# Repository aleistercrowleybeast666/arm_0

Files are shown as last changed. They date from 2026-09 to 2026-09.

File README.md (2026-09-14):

# arm_0

六轴机械臂机械 CAD。当前唯一正式主工程为 **[mechanical/freecad/arm_0.FCStd](mechanical/freecad/arm_0.FCStd)**，FreeCAD 文档标签为 `arm_0 | Prototype 0`。

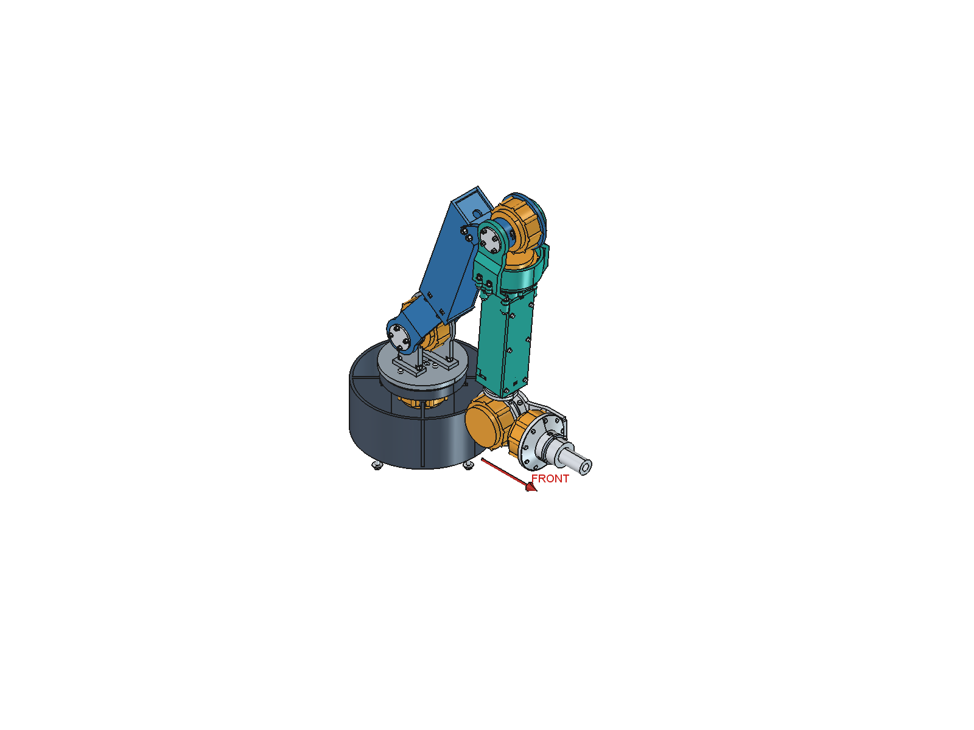
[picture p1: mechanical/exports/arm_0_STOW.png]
arm_0 前折 STOW


当前进度：Prototype 0冻结前紧固与首次审图整理。当前CSV和V4验证为本轮依据，ZIP由白名单脚本单独生成并忽略于Git。

## 当前入口

| 内容 | 文件 |
|---|---|
| 我们自己的主装配 | [arm_0.FCStd](mechanical/freecad/arm_0.FCStd) |
| 参数 | [arm_0_parameters.json](mechanical/arm_0_parameters.json) |
| 完整 STEP | [arm_0.step](mechanical/exports/arm_0.step) |
| 冻结拓扑与当前审图报告 | [arm_0_v3_review.md](mechanical/docs/arm_0_v3_review.md) |
| 装配顺序 | [assembly_concept.md](mechanical/docs/assembly_concept.md) |
| 待解决事项 | [unresolved_issues.md](mechanical/docs/unresolved_issues.md) |
| 文件清单 | [arm_0_files.md](mechanical/docs/arm_0_files.md) |
| PAROL6 参考装配（仅本地） | `mechanical/freecad/PAROL6_reference_assembly.FCStd` |
| CyberGear 参考 | `CyberGear_Detail.FCStd` 与 `CyberGear_Envelope.FCStd` |

旧侧向错层方案完整归档在 [mechanical/legacy/v2](mechanical/legacy/v2/README.md)，标记为 SUPERSEDED。上一个35 mm腕距的大框腕部保存在 [V3腕部快照](mechanical/legacy/v3_box_wrist/README.md)。第一阶段 `Arm_v1_*` 文件也仅为历史。它们的姿态和验证结果不适用于 V3。

## V3 结构

- 当前尺寸为180 / 320 / 290 / 60 / 86 / 90 mm；用户确认将J5→J6的Flange从35改为86 mm。原轴序/转向保持，两根主体盒梁回到Y=0。
- J2由大臂双叉包住，J3由小臂双叉包住；短输出hub加对侧短轴颈，取消长贯穿传动轴。
- J3定子仍固定在大臂。J4电机包络中心前移到距J3约63.75 mm处，扭矩管随roll转动，将动力传到腕部。
- J5/J6在伸直姿态前后排列，移除两层大框；J6_OnePieceConnector是一体金属连接件，J5采用输出侧可拆轴承座。工具接头可拆。
- 采用前折STOW；HOME为其附近的小幅前向展开。启动路径使用不超过2°的关节插值采样检查，不能理解为解析连续碰撞证明或实机安全认证。

当前为工程粗模与静态试装候选。电机接口为REFERENCE-DERIVED / HARDWARE VERIFY；轴承未采购定型，载荷、打印工艺和金属件加工配合尚待验证。J2额定转矩问题仍待解决；单侧金属连接件的刚度、夹紧和轴承力矩能力也需核算。Flange变化后的姿态和包络已重算，ArmDesigner中的历史参数不会自动同步。

## 使用 FreeCAD

打开 `arm_0.FCStd`，选择 PoseController 的 CurrentPose，再运行 `mechanical/scripts/SetArm0Pose.FCMacro`。仅修改下拉框不会自动移动实体。

修改 MasterParameters 后运行 `RebuildArm0.FCMacro`，生成CUSTOM副本并另存；表格不会自动重建几何，也不会写回JSON。原基线中Flange已按本轮授权调整为86 mm，该尺寸更改后需重新验证完整运动；其余五项尺寸保持锁定。本次冻结整理不重新搜索姿态；局部修改后复核已冻结的四姿态与两条启动路径。

当前复核与交接脚本：`validate_assembly_arm_0.py --full`、`handoff_arm_0.py`、`tables_arm_0.mjs`、`ReviewArm0.FCMacro`、`review_freeze_arm_0.py`、`pack_arm_0.py`。FreeCAD脚本使用FreeCAD自带Python；CSV脚本使用配置了@oai/artifact-tool的Node运行时。先通过几何与拆装检查，再导出、渲染、提交代码，最后白名单打包，ZIP不推送。

`ReviewArm0.FCMacro`用于生成原生CAD截图，应在独立FreeCAD进程运行，结束后关闭该进程。参考几何不参与主模型构建，参考研究需要的额外下载见 [来源记录](mechanical/docs/reference_license_notes.md)。`reference/`、原始SolidWorks文件、含上游网格的参考文件、说明书摘录、缓存和备份均不推送。

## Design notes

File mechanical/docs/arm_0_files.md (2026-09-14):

# arm_0 当前文件入口

- mechanical/freecad/arm_0.FCStd：我们自己的正式主CAD，Prototype 0。
- mechanical/exports/arm_0.step：当前HOME整机；同目录四姿态与J2/J3/J4/腕部PNG由ReviewArm0.FCMacro生成。
- mechanical/arm_0_parameters.json：冻结尺寸/姿态与图片来源硬件参数。
- mechanical/docs/fastener_schedule.csv、arm_0_BOM.csv：当前紧固件接口和物料表。
- mechanical/docs/assembly_manifest.csv、joint_datums.csv、parameter_summary.csv：SolidWorks重装与轴基准。
- analysis/v4/assembly_validation.json：本轮含紧固件的完整几何/拆装检查；同目录handoff_export_checks.json记录STEP回读。
- mechanical/handoff/solidworks：白名单交接暂存目录，Git忽略。
- dist/arm_0_SW_handoff_20260914.zip及.sha256：首次审图ZIP及哈希，Git忽略，单独交接。

reference目录、PAROL6参考装配和CyberGear原始详细参考仅供本地参考；不是我们自己的机械臂，也不进入Git或ZIP。旧版几何、旧搜索与analysis/v3等历史报告保留用于追溯，不应用于本轮改动后的紧固装配。当前检查以analysis/v4为准。

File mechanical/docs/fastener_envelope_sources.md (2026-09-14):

# 标准紧固件包络依据

仅使用M3/M4/M5。CAD用简化头部、光杆、垫片和螺母，不建真实牙型。螺杆显示直径为公称值减0.2 mm，啮合段用简化芯径；结构通孔仍按Ø3.4/4.5/5.5 mm建模。该简化不改变M3/M4/M5采购规格，实际螺纹与全直径配合需试装复核。螺钉长度尚未采购定型；CAD中的夹层与1 mm电机螺纹占位用于空间审查，不能解读为推荐有效旋入深度。

|规格|内六角头直径/高|六角螺母对边/高|防松螺母高|内六角工具对边|
|---|---|---|---|---|
|M3|5.5 / 3|5.5 / 2.4|4|2.5|
|M4|7 / 4|7 / 3.2|5|3|
|M5|8.5 / 5|8 / 4|5|4|

来源：[Performance Fasteners ISO 4762产品尺寸表](https://www.performancefastenersltd.co.uk/_files/ugd/aa5dc8_659865f859d941c2905d0a253d751077.pdf)、[Westfield DIN 985产品尺寸表](https://www.westfieldfasteners.co.uk/Standards/Nut-HexNy-M.html)、[Bossard六角螺母目录](https://bossard.partcommunity.com/3d-cad-models/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)。这是几何包络依据，不代表已经选定供应商品号、材料等级或新版标准认证。

M3/M4垫片占位外径7/9 mm、厚0.5/0.8 mm，M5底座大垫片外径15 mm、厚1 mm；均为待确认的空间包络。螺母采用理想六角外接轮廓，保守覆盖尖角。

打印件正式连接禁止使用热熔铜螺母、塑料攻丝、自攻螺钉或胶粘主承力。金属加工件允许M3/M4内螺纹。螺母槽在拆盖板或按记录拆开子装配后可取出，不形成永久封闭腔。

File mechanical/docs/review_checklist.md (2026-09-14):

# arm_0 第一次审图检查单

| 项目 | 本轮输出 / 判定依据 | 审图动作 |
|---|---|---|
| 轴系冻结 | 180/320/290/60/86/90 mm，UpperLane=FoldLane=0；joint_datums.csv | 核对J1～J6父子与正角轴，不改姿态规避局部问题 |
| 连接与孔用途 | fastener_schedule.csv、hole_function_register.csv | 逐编号对应CAD螺钉、A件通孔与金属接收端；核对是否残留无用途工艺孔 |
| 打印件可拆性 | 可更换螺母、侧向退出槽、盖板最后装 | 按表中前置拆件清单实物试装，确认没有封闭在打印件内的螺母 |
| 四方连接块 | 用户指定M4第五行，90°独立板材接口使用，当前安装0 | 采购后确认真实孔深、内孔是否相交，正面孔端距 |
| 轴承与压盖 | 肩座、M3通孔和金属接收端，独立轴承占位 | 核定轴承型号/预紧/公差，确认拆卸方向、剩余壁厚 |
| J4扭矩管 | 两端支承、金属夹紧、角部线槽 | 检查线槽和旋转件间隙，验证夹紧力与抗滑移 |
| J5/J6 | 前后排列、一体金属连接件、可拆工具接头 | 重点核算单侧刚度、螺钉头凹座与夹紧段 |
| 整机几何 | assembly_validation.json记录四姿态和两条≤2°路径 | 检查最小间隙位置和台面锚栓向下延伸；不能按模型包络推断螺钉长度 |
| 拆装工具 | 直线内六角35 mm预算，螺母12 mm退出包络 | 检查真实扳手弯头/套筒与手部空间；确认分阶段拆装顺序可执行 |
| STEP导入 | 所有文件独立回读；handoff_export_checks.json | 在SolidWorks运行Import Diagnostics并核对实体数和单位 |
| 生产准备 | 当前不发布 | 完成负载、材料、加工、公差、螺钉啮合、实物试装后另行评审 |

CAD自动检查只覆盖模型定义的包络。图纸未核定的硬件数据明确保留TBD；不把待测内容勾选为确认项。

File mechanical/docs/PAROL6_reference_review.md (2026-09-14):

# PAROL6 整体参考装配与结构审查

来源提交 `3892e9c85c1f6d8041cda01c47c9db9d18b30ad8`，根许可证GPLv3。本文件补充上一轮的目录审查，结合URDF、STL、装配手册与BOM。只用于研究，不导入我们的arm_0。

## 已装配的结果

`freecad/PAROL6_reference_assembly.FCStd`，7个可独立显隐的实体网格link：base_link、L1…L6，另有world组。关节保留原名base_joint、L1…L6，保留父子关系、轴向和原点属性。

读取 `PAROL6_URDF/PAROL6/urdf/PAROL6.urdf` 的visual mesh、visual origin、joint origin与axis。按父→子拓扑递推，以全部关节角0作为装配姿态；URDF的RPY使用Rz(yaw)Ry(pitch)Rx(roll)。本库STL数值也是米：例如base网格X范围-0.1775…0.05，因此**STL与关节xyz都乘1000**后进入FreeCAD毫米环境。未混用惯性原点，也未重复加载collision mesh。

已经用FreeCAD生成整体截图 `exports/PAROL6_reference_assembly.png`，形态与手册整体构型一致；导入详情 `analysis/stage2/parol6_import.json`。这是静态参考装配，未验证真实限位、负载和运动学solver。

## J1/J2/J3布置与归属

1. J1：手册59…78页为肩部/转台装配，79…86页为底座。电机、减速器、联轴器、J1_rotation_shaft和皮带分工，不是一个电机外壳直接承受全部回转弯矩。第80页底座安装两只Bearing3，BOM指定HR32907J一类锥滚子轴承。可借鉴独立支承及装配可达性。
2. J2：肩部电机驱动大臂，手册70…76页含成对轴承、J2_shaft和后压板。URDF的L2相对L1偏移(23.420721,0,110.5) mm，RPY绕X约-90°，关节自身轴为+Z，经父变换后成为水平轴。不要把原URDF的局部Z误解成世界竖轴。
3. J3：手册50页在大臂装两只Bearing2；52页安装J3大带轮；53页把Stepper2及20:1减速器装在**大臂上**；56页再连接前臂，92页左右才补装J3传动带。由这些装配步骤可确认其J3驱动固定于父大臂，输出通过皮带到肘轴。电机靠近大臂近端，不等于本项目“CyberGear直接位于肘端”。

URDF的L3相对L2为(0,-180,0) mm，并带约(π,0,-π/2)旋转、局部轴-Z；这提供了180 mm原中心距和分段坐标证据，不能直接照抄到320 mm大臂。

## 折叠与腕部

手册53/56页及原STL显示，大臂是偏置的外侧承力件，前臂/肘部转动件在旁侧连接；轴承、轮和盖板分别布置，避免把两段实体简单堆在同一中心平面。局部轮廓让位、侧面间距与轴向堆叠一起影响折叠。本轮未用参考URDF限位证明任何175°或180°极限。

手册25…36页：J5_part轴承、J5皮带轮及走线孔、前臂壳体和J4_output_pulley。39…47页：肘壳、J4皮带和后轴承压板。20…23页：末端步进电机/10:1减速器与AXK3552型轴向支承。腕部通过独立轴承、近置的正交轴以及远置/侧置传动降低端部堆叠长度，不是三只同规格电机依次串接。

URDF中L4→L5有176.35 mm偏移，L5→L6的joint origin平移为0但转轴正交；相交轴不意味着实际壳体和电机没有体积。这个事实可用于检查我们的腕部布局，不能据此把其腕长或减速器尺寸照搬。

## 借鉴与不匹配

可借鉴：分体壳和维护盖、轴承止口/压板、把主要弯矩引入独立支承、先装驱动再合壳、穿线与螺钉访问孔、父连杆安装J3驱动。

不匹配：NEMA步进电机、20:1/10:1外置减速器、HTD皮带/大轮、原锥滚子轴承尺寸、原载荷与控制限位。本项目CyberGear自带减速且关节中心距不同，重载能力不能借用PAROL6参数。

许可证/商业化：原几何、STL、URDF和装配文件保留在参考层，不缩放或改名作为我们零件。GPLv3及依赖文件自己的条款须按实际发布内容核实，本轮只记录事实，不给出商业法律清权结论。

已阅读来源：`Building instructions/Parol building instructions.pdf`（101页；重点检查20…58、59…86及J3皮带相关步骤，视觉检查26、53、56页）、`BOM/BOM.md`轴承/电机/减速器/传动条目、URDF全部link/joint/visual。没有声称逐一评审所有螺钉或全部原装配约束。

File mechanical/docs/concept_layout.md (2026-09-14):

# 六轴机械臂 v1 构型

本版是可运行、可调整、可做包络检查的概念粗模。电机尺寸、载荷、支承轴承与线缆未确认，因此“无包络穿透”不能等同于可制造或整机工程定型。

## 尺寸与坐标

| 主参数 | mm | 定义 |
|---|---:|---|
| BaseHeight | 180 | 桌面到 J2 轴线高度 |
| UpperArm | 320 | J2—J3 轴线上同一横向基准点之间距离 |
| Forearm | 290 | J3—J4 基准点中心距 |
| Wrist | 60 | J4—J5 基准点间距 |
| Flange | 35 | J5 到 J6 输出端面/法兰基准点 |
| Tool | 90 | J6 输出端面至 TCP，包含 6 mm 接口板及 84 mm 工具占位 |

坐标：世界 X 向前，Y 横向，Z 向上。J1 绕 +Z；J2、J3 绕各自局部 -Y，正角抬高 +X 连杆；J4 绕小臂 +X；J5 绕 J4 转动后的 -Y；J6 绕输出工具 +X。全部角度按右手定则，以全伸展为零。这里的 HOME/STOW 是本轮新定义候选值，未取得旧仿真的同名姿态。

新增横向假设：大臂主梁中心 UpperLane=-75 mm；小臂及腕轴线所在平面 FoldLane=+70 mm。两根主梁中心相隔 145 mm，宽度各 20 mm，平行折叠时仅主梁侧面之间名义间距 125 mm。这个较宽的首版让位量优先验证可折叠性，尚不是紧凑宽度优化结果。J2/J3 的轴线沿 Y，无唯一轴向“中心”；主骨架统一在 y=+70 取代表点，保证 320/290 是真实三维基准点距离。

全伸展 TCP=(795,70,180) mm。795 是沿 X 的长度和；引入侧向偏置后绕 J1 的实际水平半径为 sqrt(795²+70²)=798.08 mm。回导时必须带上 70 mm 偏置，不能仅回传六段长度。

## 六电机优先布局

所有黄色圆柱暂按 Ø80×50 mm，未经厂家或用户 STEP 验证。下表区间用各自上游 link 的局部坐标表示。

| 电机 | 定子所属刚体 | 位置与安装思路 |
|---|---|---|
| J1 | ground | 底座内竖直，z=25…75；输出盘带动肩座 |
| J2 | yaw | 肩轴后侧 y=-52…-2，电机不随大臂俯仰；输出侧经局部 dog-leg 转到外侧主梁 |
| J3 | upper | 大臂肘端 x=320，y=-52…-2；定子随大臂，绝不随 J3 转角带动的小臂旋转 |
| J4 | fore | 小臂末端轴向后置，距 J4 基准点 x=-60…-10；随小臂整体移动 |
| J5 | roll | 距 J4 x=60，侧面 y=-100…-50；J4 转 180° 将其翻到外侧 |
| J6 | pitch | 相对 J5 x=-15…35；定子在 J5 回绕支架内，前端对准法兰基准，完整保留 90 mm 工具段 |

J5 输出支架从 J6 电机侧边绕到其后端，避免横向轴/支架穿过 J6 圆柱包络。电机转子内部没有建模，轴端短圆柱只是连接接口示意；安装孔、真实输出盘与承载轴承需替换。

## 草图到工程结构

本轮未收到草图图片，仅依据 prompt 的文字解释：长外侧大臂、小臂沿侧边折回、肘部让位。具体实现为肩端 x≈60 的局部 dog-leg，将输出接口转接到 y=-75 的长主梁；肘端固定 J3 电机，动侧仅保留短轴/根部连接，把小臂移至 y=+70；小臂折回时两根梁平行错位，不在中央迎头相撞。

J3 定子固定在大臂，使电机主体不进入小臂绕肘的转动扫掠体，降低肘部动侧体积。但 J3 输出的横向悬伸仍会带来弯矩；后续必须补独立支承轴承、实际输出法兰、安装过渡件并核算挠度，不能让未经验证的电机轴承独自承担整臂外载。

## 姿态与展开次序

| 名称 | J1 / J2 / J3 / J4 / J5 / J6（deg） |
|---|---|
| STOW | 0 / 75 / 175 / 180 / 90 / 0 |
| SAFE_UNFOLD | 0 / 75 / 90 / 180 / 90 / 0 |
| WRIST_NEUTRAL | 0 / 75 / 90 / 180 / 0 / 0 |
| WRIST_TURNED | 0 / 75 / 90 / 0 / 0 / 0 |
| HOME | 0 / 45 / 65 / 0 / -80 / 0 |

关键顺序：保持腕朝外，先开 J3；在展开位置把 J5 回中；再转 J4；最后进入 HOME。反向路径即本版收纳候选路径。不把这些名称当成控制器安全认证或真实硬件限位；采样结果见 `validation_report.md`。

对于更深折叠，本轮比较 J4=0 / J5=-90 的朝内腕和 J4=180 / J5=90 的朝外腕。J3 角度探索到 200°，只是几何扫描，不能由此设置硬件限位；线缆、编码器零点与止挡均未建模。

## 蛋糕场景与人工边界

工作区未找到 ArmDesigner、原仿真或默认场景文件。临时假设蛋糕中心 (500,70,150) mm，半径100，高100；顶面200，TCP在210做向下接近。只验证近/中/远代表点和650 mm半径处的一个向下姿态，不代表整个蛋糕曲面、障碍物、连续任务轨迹或刚度都满足要求。完整蛋糕 CAD 与场地碰撞尚未纳入自碰撞报告。

后续优先：真实电机STEP及孔位 → 额定连续扭矩/热/质量与末端载荷 → J2/J3支承和轴向宽度优化 → 真实轴限位和线缆 → 连续碰撞与完整任务路径 → 再细化孔、壁厚与工艺。小臂侧向嵌套成立的代价是横向体积与悬伸，后续应进一步收窄。

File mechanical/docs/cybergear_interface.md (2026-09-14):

# CyberGear 接口核对（第二阶段）

2026-09-14。来源：[freezeLUO/CyberGear](https://github.com/freezeLUO/CyberGear)，提交 `db450fa86455ab1edd0c744fc6aef4e810573014`。原有 `reference/cybergear/README.md` 保留，因此仓库位于 `reference/cybergear/upstream/`，未覆盖已有内容。

## 使用文件及证据等级

目录 `Cybergear model(SOLIDWORKS 2022 & STL)/` 已包含 `Cybergear.SLDASM`、`motor.SLDPRT`、`rotor.SLDPRT`、`Cybergear - motor-1.STL`、`Cybergear - rotor-1.STL`、`CAD.png`、`cybergear.png`。另有 `doc/CyberGear微电机使用说明书.pdf`。

本轮直接导入两份 STL，未读取 SolidWorks 特征树，没有可用 STEP。Detail 中原始网格的定子/转子分开保存；Envelope 用独立解析实体重建。两份源 STL 均为闭合网格，面数分别2342和1230。外部零件现在已齐备，但未在 SolidWorks 验证全部装配约束/配置。

以下“图纸标注”指已读取该仓库提供的尺寸图与说明书，不表示用户手中实物已检验，也不将第三方仓库视为已确认的最新厂家发布源。

| 数据 | 值 / 状态 | 依据 |
|---|---|---|
| 主体直径 | Ø75±0.1 mm，图纸标注 | CAD.png / 说明书PDF第3页 |
| 主体轴向厚度 | 25±0.2 mm，图纸标注 | 同上 |
| 后部突出长度、直径 | 8.5 mm、Ø63 mm，图纸标注 | 同上 |
| 前端固定止口 | Ø43，图中公差0/-0.02，突出约2 mm | 同上，配合需实物复核 |
| 整体轴向包络 | 36.5 mm，STL测量 | 不是把25+8.5直接当总厚度；包含输出突出 |
| 原始定子网格包围盒 | 79.62994 × 35.50000 × 79.42331 mm | 原STL坐标轴为X/Y/Z，Y为轴向 |
| 原始转子网格包围盒 | 31.90269 × 8.00000 × 31.99966 mm | 多边形离散使包围盒略小于名义Ø32 |
| 输出盘外径、中心孔 | Ø32、Ø10，STL轮廓拟合 | 不能作为制造公差图 |
| 前部固定孔 | 9-M3，深8，图纸标注 | 螺纹未实体建模 |
| 前部固定孔中心 | 拟合分布在约Ø75圆上 | 各坐标直接从STL平面边界拟合，记录在JSON；不是凭空均布 |
| 输出孔 | 6-M4，深6，约Ø24分布 | 图纸 + STL拟合；另有3个Ø4定位孔，未拿来替代螺钉孔 |
| 后部固定孔 | 图示6-M3、Ø71分布 | 当前STL简化细节未完整对应，未用于我们安装板 |
| 线缆接头 | 后侧24V/CAN一体端子 | 说明书第6页；具体安装角、插头/线缆尺寸待确认 |

孔拟合程序区分转子前面半径约2.025 mm的六个网格孔与半径约2.000 mm的三个定位孔。**这些网格圆孔直径不是螺纹检验结果**。安装板采用独立的M3/M4通孔参数3.4/4.5 mm，均为PROVISIONAL。

## 坐标、固定端和输出端

CyberGear局部 +Z 为出轴方向，输出盘最前端平面为 Z=0，转轴穿过(0,0,0)。固定安装面为 Z=-3；机体背端约 Z=-36.5；后部电子/接口区域约 Z=-36.5…-28；主体约 Z=-28…-3；固定止口约 Z=-3…-1；转子包络 Z=-8…0。

原网格轴向为 -Y。统一变换为绕原X轴-90°，再平移(-40.8229898,-79.0031928,+0.14544068) mm。没有分别把两个网格各自居中，从而保留了原装配相对位置。

`motor` 作为固定外壳/定子，`rotor` 为旋转输出侧。Master中每台电机的定子跟随父连杆，输出盘跟随子连杆。特别是J3定子属于 `upper`，不是 `fore`。

连接器预留为局部 +X 侧24×16×14 mm矩形，Z=-37…-23，**方向和尺寸都是临时预留**；并非已从真实插头确认。源STL没有完整接插件及弯曲线束，所以Detail也不能单独完成最终线束干涉验证。

## 两层文件

- `freecad/CyberGear_Detail.FCStd`：规范坐标后的原始STL参考，供视觉、平面和孔位对照。不能直接替代安装公差/螺纹深度图。
- `freecad/CyberGear_Envelope.FCStd`：主体、后部突出、9个安装耳、固定止口、独立输出盘、安装孔、轴线、关键面与连接器预留。不是上一版80×50圆柱。
- `analysis/stage2/cybergear_plane_loops.json`：拟合圆心/半径/误差。
- `analysis/stage2/cybergear_interface_data.json`：规范坐标和采用数据。

未确认：用户实际硬件版本、孔位公差、安装耳承载、定位销用途、螺钉有效啮合/沉孔、轴承允许外载、真实连接器与线束、原始模型再分发许可。它们仍是释放加工前的核对项目。

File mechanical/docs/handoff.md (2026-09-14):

# 人工接续与回导约定

1. 打开 HOME/STOW 原生 FCStd；树中有 MasterParameters、MasterSkeleton 及 ground/yaw/upper/fore/roll/pitch/tool 七个刚体组。六电机各为独立对象，可检查其 RigidOwner 属性。
2. 用 SolidWorks 检查根目录 SLDASM 是否缺件/含虚拟件，导出完整 STEP，确认 CyberGear 实际型号、外径、轴向长度、连接器、输出面和重量。按 `reference/cybergear/README.md` 放置；本轮模型只是 Ø80×50 假设。
3. 保持320/290中心距，完善肩/肘独立轴承、轴和安装孔，核对145 mm主梁侧向间隔能否缩小。当前细杆、薄板、短轴只是力流连接示意，未定壁厚与材料。
4. 确认蛋糕平台坐标、尺寸、工具形状/重量、工作姿态、速度、急停及最大载荷，再做静力矩、加速度、刚度、疲劳、温升与底座倾覆分析。本轮未指定材料或真实质量，不能给出有效负载结论。
5. 测量线缆弯曲半径、接头朝向及J3/J4可用角度，设置真实止挡和标定零位。验证连续扫掠与完整任务路径，特别是深折叠和从HOME切换到负J3的蛋糕姿态。
6. 参数/真实实体每次变化都重新生成检查；5 mm电机间隙目标不包含线束，接口面的接触/2 mm转接间隙属于粗模接头，需逐一审核。

## ArmDesigner 接口

`analysis/armdesigner_bridge.json` 含四个主姿态的六轴世界坐标、方向、上游帧 quaternion_xyzw 和 TCP；`analysis/motion_checks.json` 还包含蛋糕姿态和展开路径。参数从 `mechanical/parameters.json` 读取。

这是数据交换准备文件，未修改 ArmDesigner，也不声称已兼容其既有 schema。本工作区没有 ArmDesigner 源码，后续需映射它的角度正负、零位、单位和旋转约定。不要复用参考 URDF 的惯量或限位。

运动链（列向量、左乘父帧，长度mm）：

```text
Rz(q1)
T(0,0,BaseHeight) Ry(-q2)
T(UpperArm,0,0) Ry(-q3)
T(Forearm,FoldLane,0) Rx(q4)
T(Wrist,0,0) Ry(-q5)
T(Flange,0,0) Rx(q6)
T(Tool,0,0) → TCP
```

大臂实体偏置 UpperLane 影响碰撞几何；FoldLane同时影响运动学。主骨架的J2/J3基准点位于各自轴线上y=FoldLane位置，其方向数据是关节转动轴而非电机型号输出符号约定。电机实际转向、减速比和编码器单位需另行标定。

## 本轮未完成

- 真实CyberGear导入和孔位匹配；Y-arm参考审查。
- 支承轴承、真实转子/输出法兰、紧固件与装配公差；不存在最终可制造BOM。
- 六轴完整自由度空间与连续碰撞、环境障碍及食品接触工具设计。
- 连续扭矩/热、材料强度和刚度；没有把“几何可达”当成“650mm处可带载作业”。
- 最终工业外观、工艺、工程图和控制器安全路径。

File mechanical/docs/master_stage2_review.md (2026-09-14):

# 第二阶段：机械 CAD Master 使用与验证

本轮产物为独立建模的工程粗模：J1～J3可进行模型核对、切片和静态打印试装，J4～J6为装配占位。尚不能作为带载电动样机的制造发布版本。

## 打开与操作

用 FreeCAD 1.1.3 打开 [Robot_Master.FCStd](../freecad/Robot_Master.FCStd)。默认保存 HOME。模型含六根 Axis_J1…J6、六个 Origin_J1…J6、MasterParameters 表格、PoseController、按总成分组的独立 Body；共41个物理组件对象，另有6个可隐藏的线缆预留体。

1. 切换姿态：选择 PoseController，在属性 CurrentPose 中选择 HOME、STOW、SAFE_UNFOLD 或 CAKE_APPROACH，然后运行 [SetRobotPose.FCMacro](../scripts/SetRobotPose.FCMacro)。单改下拉框不会自动更新实体。
2. 改尺寸：编辑 MasterParameters 后运行 [RebuildRobotMaster.FCMacro](../scripts/RebuildRobotMaster.FCMacro)，创建新的 CUSTOM 文档，再另存为。修改表格后必须先重建几何，再切姿态；表格不会自动驱动所有布尔实体，也不会写回 JSON。
3. 批量主入口：[master_parameters.json](../master_parameters.json)。重建脚本会覆盖其管理的同名输出，人工修改请另存新文件。
4. PowerShell 在 Arm 根目录运行 `& .\mechanical\scripts\build_stage2.ps1`，依次重建参考、Master、静态检查、STEP回读和STL。截图单独运行 [ReviewStage2.FCMacro](../scripts/ReviewStage2.FCMacro)。此截图宏打开并保存四份生成文档，运行完关闭该 FreeCAD 窗口，宜使用独立进程。

这些 Body 有命名的建模阶段与最终 Tip，但不是全部由可交互草图约束驱动。尺寸变化通过 Python 重建；局部人工修改应保存在副本中。

## 参考与电机接口

- PAROL6：URDF中 xyz、rpy、关节层级和轴向完整解析；网格和位移由米转毫米。已重建7个网格连杆及world，独立 App::Part 保留link/joint名，可分别隐藏。[参考装配](../freecad/PAROL6_reference_assembly.FCStd) / [分析](PAROL6_reference_review.md)。
- Thor：实际存在 `freecad-src/Assembly.FCStd`，六个总成链接可解析；其中Art4/Art56聚合包围盒含异常极大值，未据此宣称全装配几何验证通过。官方装配网页请求超时，已记录限制。[分析](Thor_reference_review.md)。
- CyberGear：已克隆到原有目录内的 `reference/cybergear/upstream`，保留原README和用户SLDASM。用上游两份STL组成 [Detail](../freecad/CyberGear_Detail.FCStd)，结合说明书图纸与STL平面孔环提取建立 [Envelope](../freecad/CyberGear_Envelope.FCStd)。没有上游STEP，未声称已直接读取SolidWorks装配。

电机原点定义为输出面中心，局部+Z为输出方向。定子主体Ø75、长度25，后盖Ø63、厚8.5，固定止口Ø43；相对输出面，定子后端为Z=-36.5。前面9-M3固定接口与输出6-M4接口分开建模，输出盘Ø32。说明书标称、网格测量、简化和假设逐项区分，见 [cybergear_interface.md](cybergear_interface.md)。线缆24×16×14预留体的朝向仍是假设；Detail可辅助核对孔位，不能取代实物测量或厂家工程图。

PAROL6/Thor几何未进入我们的Master。来源与许可证事实见 [reference_license_notes.md](reference_license_notes.md)；CyberGear仓库未发现LICENSE，不推定有商业再分发许可。

## 六轴、归属和实体构型

| 关节 | 定子所属刚体 | 转子驱动 | 轴向约定 |
|---|---|---|---|
| J1 | 地面底座 base | 肩架 yaw | 世界+Z |
| J2 | 肩架 yaw | 大臂 upper | 肩架局部-Y |
| J3 | 大臂 upper | 小臂 fore | 大臂局部-Y |
| J4 | 小臂 fore | 腕roll | 小臂局部+X |
| J5 | 腕roll | 腕pitch | roll局部-Y |
| J6 | 腕pitch | 工具 tool | pitch局部+X |

表中为运动学正角轴向；J2/J3/J5的电机输出面朝局部+Y，与正角轴向相反。后续控制坐标映射需明确此符号，当前不涉及控制代码。

BaseHeight=180、UpperArm=320、Forearm=290、Wrist=60、Flange=35、Tool=90 mm，MotorCount=6。用本工作区第一阶段的自身运动学框架，实际检查Master轴线代表点之间的320/290/60/35 mm。

J2、J3是沿Y方向的轴线；其尺寸代表点取y=70 mm，不等于电机输出面中心所在的y=0平面。J1代表点在地面，其实际输出面在z=90 mm。这些是同一轴线上的不同点，不增加虚构的连杆长度。J2高度为180 mm。零角完全伸展时TCP为(795,70,180) mm。

本工作区没有可用于交叉核验的ArmDesigner源码，因此只确认提供的基线尺寸和本地运动学，未声称已完成与ArmDesigner的零位、符号、坐标系回归。

- J1：Ø210开口底座，4 mm壁/径向筋，带嵌件孔的安装柱，可拆电机板、带肩支承座及旋转平台。
- J2：左右支撑板、安装脚/筋，左侧电机，右侧带肩轴承座及压盖，大臂接口与金属贯穿轴构成双侧支承。
- J3：定子固定在大臂末端壳体，可拆前固定板和对侧轴承板；动侧为输出hub、轴和小臂根部。单独改变q3的检查确认定子不动。
- 大臂：4 mm壁与筋的盒壳，24/90 mm过渡形成约14.93°浅弯；X=180处拆为两段，用4-M4连接，盖板可拆。J2→J3始终320 mm。
- 折叠：大臂主壳中心y=-62，小臂y=+70，两者横向相隔132 mm。以侧向错层、局部让位及短支架实现回折，宽度仍待优化。
- J4～J6：独立定子/转子、安装占位与局部让位，保持60/35 mm轴间距及90 mm工具长度；未完成腕部制造细节。

## 最终几何检查

报告：[master_checks.json](../../analysis/stage2/master_checks.json)、[deliverable_checks.json](../../analysis/stage2/deliverable_checks.json)、[STOW余量检查](../../analysis/stage2/stow_margin_check.json)。测试采用包围盒筛选后BRep交集，交叠体积阈值0.1 mm³；接触不作为穿透。结果限于当前简化实体和列出的离散姿态。

| 姿态 | J1/J2/J3/J4/J5/J6（度） | 跨刚体穿透 | 线缆预留冲突 |
|---|---|---|---|
| HOME | 0 / 45 / 65 / 0 / -80 / 0 | 未检出 | 未检出 |
| STOW | 0 / 75 / 165 / 180 / 90 / 0 | 未检出 | 未检出 |
| SAFE_UNFOLD | 0 / 75 / 90 / 180 / 90 / 0 | 未检出 | 未检出 |
| CAKE_APPROACH | 0 / 57.9412 / -77.3316 / 0 / -70.6096 / 0 | 未检出 | 未检出 |

每个姿态检查688组跨刚体组件对，另外检查132组同刚体零件对，均未检出大于阈值的实体穿透。六电机定子简化外形之间最小距离约19.93 mm，发生在J5/J6；这不是所有机械件的最小间隙。线缆预留检查只针对其他刚体，不包括本刚体内部走线。STOW肩部对侧轴承支撑到J4壳体约9.24 mm。

STOW采用J3=165°：试过的168°、170°已有肩部支撑与J4壳体穿透，175°出现多处肩/腕/平台冲突，不能把175°当作可用姿态。小臂可以向大臂一侧折回，腕部仍影响最终收纳范围。没有做连续路径扫掠、线束弯曲仿真、限位开关或真实螺钉工具包络验证；SAFE_UNFOLD只是姿态名称，不是已验证安全轨迹。第一阶段的轨迹结论不能沿用。

15个打印候选实体均为有效单一Solid；本轮重点导出其中J1～J3的13个封闭STL用于试装。完整STEP回读得到41个有效Solid，总体积差约0.00464 mm³；J1/J2/J3子STEP分别为9/8/11个Solid。四份STEP均通过有效性、实体数量和体积回读检查。

## 制造性与未完成工作

主体壁4 mm、筋4 mm、盖4 mm，局部电机板6 mm、平台8 mm；M3/M4/M5通孔3.4/4.5/5.5，嵌件预孔、轴承座和同轴配合均标PROVISIONAL。J2/J3轴承20×42×12占位带肩和压盖，J1支承80×100×10占位未定具体轴承类型。金属轴与输出件不能随意改成打印承力件。

电机从哪一侧装、螺钉访问、轴承安装、子连杆连接及拆卸顺序见 [assembly_concept.md](assembly_concept.md)。轴锁紧、轴承预紧、螺钉有效啮合、打印材料/方向和最终加工图仍需设计，完整待办见 [unresolved_issues.md](unresolved_issues.md)。

**J2转矩是当前首要结构约束。** 以说明书质量下限314 g及参考包络的最小水平力臂，只计J3～J6四个电机，完全水平伸展时J2重力矩下界为6.627 N·m，已高于4 N·m额定转矩。尚未加入壳体、轴、工具或负载。此为保守的电机自重筛查，不是完整载荷计算；需要研究J2减速、配重/弹簧或电机重选后再进行带电带载样机。

## 导出与接续

[完整STEP](../exports/Robot_Master_coarse.step)及J1/J2/J3子总成使用HOME世界坐标；[envelope目录](../exports/envelope/)中的7个STEP则分别位于各自刚体局部坐标。
envelope是每组件的保守AABB盒，不是精确碰撞面；盒之间可能产生保守误报。使用 [armdesigner_bridge_v2.json](../../analysis/stage2/armdesigner_bridge_v2.json) 中各姿态的translation与xyzw四元数放置，不能将七份局部STEP全叠在世界原点。尚未修改或接入ArmDesigner。

全部新增CAD、脚本、导出、文档、截图和验证记录见 [stage2_files.md](stage2_files.md)。当前Arm不是Git仓库，没有初始化；三份上游来源保留在reference，第一阶段文件与用户原SLDASM保留。

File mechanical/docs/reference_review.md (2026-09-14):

# 第一阶段参考审查

检查日期：2026-09-14。原 `reference` 目录为空。普通网络克隆失败后，经授权网络重试完成两个 shallow clone（depth=1）；未删除或覆盖已有用户文件。只含当前版本与浅历史，不含完整提交历史。

## 已实际获取的来源

| 参考源 | 上游 / 本地位置 | 固定提交 |
|---|---|---|
| PAROL6 | https://github.com/Source-Robotics/PAROL6-Desktop-robot-arm / `reference/PAROL6` | `3892e9c85c1f6d8041cda01c47c9db9d18b30ad8` |
| Thor | https://github.com/AngelLM/Thor / `reference/Thor` | `286b081fe6f056d87c379b884781ef77ff6a0159` |

本轮读取 README、许可证、目录清单、PAROL6 BOM 与 URDF 开头，检查 Thor 一个 FreeCAD 文件的 Document.xml 对象结构。未逐页评审全部装配 PDF，也未对全部原始零件作几何审计。完整文件类型统计见 `analysis/reference_inventory.json`。

## PAROL6

7856 个受检查文件，其中 52 个 STL、1 个 URDF、2 个 STEP、5 个 PDF；大量其他文件属于控制软件依赖和文档资源。

- `STL/`：机械分件；其中 `mounting plates/big_base.STEP`、`small_base.STEP` 只是安装板，不能误称为完整整臂 STEP。
- `PAROL6_URDF/PAROL6/urdf/PAROL6.urdf`：关节、link、惯量及网格引用；可研究六轴串联表达方式。原尺寸、零点、限位、质量不能直接移植。
- `BOM/BOM.md`、`BOM_PDF_Legacy.pdf`：采购分类。BOM 包含 NEMA17 步进电机、行星减速器、皮带等，与本项目 CyberGear 方案不同。
- `Building instructions/Parol building instructions.pdf`、小打印平台改装 PDF、`PETG_printing.md`：可供人工继续研究装配次序和维护空间。
- `Print table/`：打印分件参考；不作为本项目制造材料和强度依据。

适合借鉴：底座—肩—肘—前臂—腕—工具的分段逻辑、工业串联构型、折叠概念。没有导入其 STL、URDF 或任何原始 CAD 到我们的机械文件。

## Thor

236 个文件；79 个 FCStd、72 个 STEP、72 个 STL。

- `freecad-src/`：原生特征树；抽查 `Art2BodyA.fcstd`，内含 1 个 Spreadsheet、22 个 Sketch、2 个 Body、Pad/Pocket、Datum 等。这支持借鉴参数入口和分件组织方式；并非认定所有零件都由统一主参数完全驱动。
- `step/`、`stl/`：交换实体与打印网格；`mods/` 是变体；`doc/` 主要是说明图片/标识，不应误称为完整装配手册目录。
- 当前仓库没有 URDF，README 指向独立 Thor-ROS 仓库；本轮未克隆该仓库。
- BOM 与装配链接在 README，指向 https://thor.angel-lm.com/documentation/bom/ 和 https://thor.angel-lm.com/documentation/assembly/ 。未声称已下载这些页面的全部装配资料。

适合借鉴：按关节拆分 FreeCAD 源文件、Spreadsheet + Sketch/Body 的工程组织。步进电机、打印齿轮、GT2 传动、原尺寸与外壳均未沿用。

## 许可证与独立重建边界

PAROL6 根 LICENSE 是 GPLv3；README 最下方同样声明 GPLv3。徽章的 alt 文本出现 MIT 字样，不能据此将其认定为 MIT 项目。Thor 根 LICENSE 是 CC BY-SA 4.0。

两者不能简单归纳为“禁止商用”：GPLv3 包含传播修改版本、源码与许可条件；CC BY-SA 4.0 允许商业使用，但对受其约束的共享/改编材料要求署名、标注修改和相同方式共享。范围应结合实际使用的文件与交付方式评估，不能以重画或重命名推断义务消失。

原文依据：[PAROL6 LICENSE](https://github.com/Source-Robotics/PAROL6-Desktop-robot-arm/blob/main/LICENSE)、[Thor LICENSE](https://github.com/AngelLM/Thor/blob/main/LICENSE)、[CC 官方条款摘要](https://creativecommons.org/licenses/by-sa/4.0/)。商业发布前仍需核实拟使用素材及相关权利；本轮不作最终法律清权结论。

**参考来源**：上述仓库的构型与文件组织信息。**我们自行重建的结构**：参数、运动链、145 mm 双侧主梁间隔、肩部 dog-leg、J3 定子归属、外置 J5 与回绕 J6 支架、所有基础几何、验证与导出脚本。脚本不读取 reference CAD/mesh/URDF；正式导出仅含本项目生成几何。参考目录保留上游 LICENSE，不把上游文件混入正式 STEP/FCStd。

Y-arm 尚未取得；CyberGear 用户装配来源与完整性未确认，详见对应预留目录 README。

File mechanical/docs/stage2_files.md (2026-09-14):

# 第二阶段文件清单

本清单列出本轮新增交付文件和更新入口；不包含FreeCAD自动备份、Python缓存和第一阶段历史产物。
依赖旧有自建运动学脚本 `mechanical/scripts/arm_model.py`，未修改该脚本。参考仓库内容保留在reference，不混入自己的Master。
机器可读大小与SHA256记录见 [deliverable_manifest.json](../../analysis/stage2/deliverable_manifest.json)。
本清单自身为 `mechanical/docs/stage2_files.md`；为避免循环哈希，清单和manifest本身不列入哈希表。

## FreeCAD 主文件

| 文件 | 字节 |
|---|---:|
| [mechanical/freecad/Robot_Master.FCStd](../../mechanical/freecad/Robot_Master.FCStd) | 664352 |
| [mechanical/freecad/CyberGear_Detail.FCStd](../../mechanical/freecad/CyberGear_Detail.FCStd) | 54811 |
| [mechanical/freecad/CyberGear_Envelope.FCStd](../../mechanical/freecad/CyberGear_Envelope.FCStd) | 32149 |
| [mechanical/freecad/PAROL6_reference_assembly.FCStd](../../mechanical/freecad/PAROL6_reference_assembly.FCStd) | 2380583 |

## 参数、脚本与宏

| 文件 | 字节 |
|---|---:|
| [mechanical/master_parameters.json](../../mechanical/master_parameters.json) | 1163 |
| [mechanical/scripts/import_parol6_urdf_to_freecad.py](../../mechanical/scripts/import_parol6_urdf_to_freecad.py) | 4526 |
| [mechanical/scripts/measure_cybergear.py](../../mechanical/scripts/measure_cybergear.py) | 2068 |
| [mechanical/scripts/cybergear_model.py](../../mechanical/scripts/cybergear_model.py) | 4639 |
| [mechanical/scripts/build_robot_master.py](../../mechanical/scripts/build_robot_master.py) | 23761 |
| [mechanical/scripts/check_robot_master.py](../../mechanical/scripts/check_robot_master.py) | 3729 |
| [mechanical/scripts/export_robot_deliverables.py](../../mechanical/scripts/export_robot_deliverables.py) | 6221 |
| [mechanical/scripts/write_stage2_inventory.py](../../mechanical/scripts/write_stage2_inventory.py) | 4433 |
| [mechanical/scripts/build_stage2.ps1](../../mechanical/scripts/build_stage2.ps1) | 567 |
| [mechanical/scripts/SetRobotPose.FCMacro](../../mechanical/scripts/SetRobotPose.FCMacro) | 666 |
| [mechanical/scripts/RebuildRobotMaster.FCMacro](../../mechanical/scripts/RebuildRobotMaster.FCMacro) | 633 |
| [mechanical/scripts/ReviewStage2.FCMacro](../../mechanical/scripts/ReviewStage2.FCMacro) | 3110 |

## STEP

| 文件 | 字节 |
|---|---:|
| [mechanical/exports/Robot_Master_coarse.step](../../mechanical/exports/Robot_Master_coarse.step) | 1604839 |
| [mechanical/exports/J1_base.step](../../mechanical/exports/J1_base.step) | 319051 |
| [mechanical/exports/J2_shoulder.step](../../mechanical/exports/J2_shoulder.step) | 189429 |
| [mechanical/exports/J3_upper_elbow.step](../../mechanical/exports/J3_upper_elbow.step) | 513500 |
| [mechanical/exports/envelope/base_envelope.step](../../mechanical/exports/envelope/base_envelope.step) | 29927 |
| [mechanical/exports/envelope/forearm_envelope.step](../../mechanical/exports/envelope/forearm_envelope.step) | 40940 |
| [mechanical/exports/envelope/shoulder_envelope.step](../../mechanical/exports/envelope/shoulder_envelope.step) | 53099 |
| [mechanical/exports/envelope/tool_envelope.step](../../mechanical/exports/envelope/tool_envelope.step) | 12827 |
| [mechanical/exports/envelope/upper_arm_envelope.step](../../mechanical/exports/envelope/upper_arm_envelope.step) | 65206 |
| [mechanical/exports/envelope/wrist_envelope.step](../../mechanical/exports/envelope/wrist_envelope.step) | 24084 |
| [mechanical/exports/envelope/wrist_pitch_envelope.step](../../mechanical/exports/envelope/wrist_pitch_envelope.step) | 18221 |

## 试装 STL

| 文件 | 字节 |
|---|---:|
| [mechanical/exports/print_fit/J1_BaseTray.stl](../../mechanical/exports/print_fit/J1_BaseTray.stl) | 299684 |
| [mechanical/exports/print_fit/J1_BearingSeat.stl](../../mechanical/exports/print_fit/J1_BearingSeat.stl) | 118884 |
| [mechanical/exports/print_fit/J1_MotorMount.stl](../../mechanical/exports/print_fit/J1_MotorMount.stl) | 192284 |
| [mechanical/exports/print_fit/J1_RotatingPlatform.stl](../../mechanical/exports/print_fit/J1_RotatingPlatform.stl) | 116884 |
| [mechanical/exports/print_fit/J2_BearingRetainer.stl](../../mechanical/exports/print_fit/J2_BearingRetainer.stl) | 63684 |
| [mechanical/exports/print_fit/J2_LeftMotorCheek.stl](../../mechanical/exports/print_fit/J2_LeftMotorCheek.stl) | 165284 |
| [mechanical/exports/print_fit/J2_RightBearingCheek.stl](../../mechanical/exports/print_fit/J2_RightBearingCheek.stl) | 95184 |
| [mechanical/exports/print_fit/J3_BearingRetainer.stl](../../mechanical/exports/print_fit/J3_BearingRetainer.stl) | 63684 |
| [mechanical/exports/print_fit/J3_FixedMotorPlate.stl](../../mechanical/exports/print_fit/J3_FixedMotorPlate.stl) | 192284 |
| [mechanical/exports/print_fit/J3_RemovableBearingCheek.stl](../../mechanical/exports/print_fit/J3_RemovableBearingCheek.stl) | 94784 |
| [mechanical/exports/print_fit/Upper_MainShell_Distal.stl](../../mechanical/exports/print_fit/Upper_MainShell_Distal.stl) | 292084 |
| [mechanical/exports/print_fit/Upper_MainShell_Proximal.stl](../../mechanical/exports/print_fit/Upper_MainShell_Proximal.stl) | 326884 |
| [mechanical/exports/print_fit/Upper_RemovableLid.stl](../../mechanical/exports/print_fit/Upper_RemovableLid.stl) | 83784 |

## 文档

| 文件 | 字节 |
|---|---:|
| [mechanical/docs/master_stage2_review.md](../../mechanical/docs/master_stage2_review.md) | 9270 |
| [mechanical/docs/cybergear_interface.md](../../mechanical/docs/cybergear_interface.md) | 4392 |
| [mechanical/docs/PAROL6_reference_review.md](../../mechanical/docs/PAROL6_reference_review.md) | 4231 |
| [mechanical/docs/Thor_reference_review.md](../../mechanical/docs/Thor_reference_review.md) | 2461 |
| [mechanical/docs/reference_license_notes.md](../../mechanical/docs/reference_license_notes.md) | 1863 |
| [mechanical/docs/assembly_concept.md](../../mechanical/docs/assembly_concept.md) | 6407 |
| [mechanical/docs/unresolved_issues.md](../../mechanical/docs/unresolved_issues.md) | 2954 |

## 原生 CAD 截图

| 文件 | 字节 |
|---|---:|
| [mechanical/exports/Robot_HOME.png](../../mechanical/exports/Robot_HOME.png) | 40255 |
| [mechanical/exports/Robot_STOW.png](../../mechanical/exports/Robot_STOW.png) | 76950 |
| [mechanical/exports/Robot_SAFE_UNFOLD.png](../../mechanical/exports/Robot_SAFE_UNFOLD.png) | 76634 |
| [mechanical/exports/Robot_CAKE_APPROACH.png](../../mechanical/exports/Robot_CAKE_APPROACH.png) | 49525 |
| [mechanical/exports/CyberGear_Detail.png](../../mechanical/exports/CyberGear_Detail.png) | 26757 |
| [mechanical/exports/CyberGear_Envelope.png](../../mechanical/exports/CyberGear_Envelope.png) | 38187 |
| [mechanical/exports/PAROL6_reference_assembly.png](../../mechanical/exports/PAROL6_reference_assembly.png) | 62522 |

## 验证与来源读取记录

| 文件 | 字节 |
|---|---:|
| [analysis/stage2/armdesigner_bridge_v2.json](../../analysis/stage2/armdesigner_bridge_v2.json) | 8936 |
| [analysis/stage2/cybergear-04.png](../../analysis/stage2/cybergear-04.png) | 174951 |
| [analysis/stage2/cybergear-05.png](../../analysis/stage2/cybergear-05.png) | 238051 |
| [analysis/stage2/cybergear-06.png](../../analysis/stage2/cybergear-06.png) | 169031 |
| [analysis/stage2/cybergear_dims-03.png](../../analysis/stage2/cybergear_dims-03.png) | 511490 |
| [analysis/stage2/cybergear_interface_data.json](../../analysis/stage2/cybergear_interface_data.json) | 1214 |
| [analysis/stage2/cybergear_manual.txt](../../analysis/stage2/cybergear_manual.txt) | 33229 |
| [analysis/stage2/cybergear_mesh_bounds.json](../../analysis/stage2/cybergear_mesh_bounds.json) | 525 |
| [analysis/stage2/cybergear_plane_loops.json](../../analysis/stage2/cybergear_plane_loops.json) | 7591 |
| [analysis/stage2/deliverable_checks.json](../../analysis/stage2/deliverable_checks.json) | 9165 |
| [analysis/stage2/environment.json](../../analysis/stage2/environment.json) | 630 |
| [analysis/stage2/gui_review.log](../../analysis/stage2/gui_review.log) | 106 |
| [analysis/stage2/master_checks.json](../../analysis/stage2/master_checks.json) | 4716 |
| [analysis/stage2/parol6_fold-056.png](../../analysis/stage2/parol6_fold-056.png) | 185951 |
| [analysis/stage2/parol6_import.json](../../analysis/stage2/parol6_import.json) | 3915 |
| [analysis/stage2/parol6_manual.txt](../../analysis/stage2/parol6_manual.txt) | 26126 |
| [analysis/stage2/parol6_upper-053.png](../../analysis/stage2/parol6_upper-053.png) | 111331 |
| [analysis/stage2/parol6_wrist-026.png](../../analysis/stage2/parol6_wrist-026.png) | 133581 |
| [analysis/stage2/stow_margin_check.json](../../analysis/stage2/stow_margin_check.json) | 3734 |
| [analysis/stage2/thor_assembly_check.json](../../analysis/stage2/thor_assembly_check.json) | 1487 |

## 更新的历史入口

| 文件 | 字节 |
|---|---:|
| [mechanical/README.md](../../mechanical/README.md) | 2737 |
| [reference/cybergear/README.md](../../reference/cybergear/README.md) | 2291 |

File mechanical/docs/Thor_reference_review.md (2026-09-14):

# Thor 参数化与总成参考

来源：`reference/Thor`，提交 `286b081fe6f056d87c379b884781ef77ff6a0159`，CC BY-SA 4.0。

本轮补查发现，`freecad-src` **确实存在 Assembly.FCStd**，不是只有散件。XML包含6个App::Link，连接AssemblyBase、AssemblyArt1、AssemblyArt2、AssemblyArt3、AssemblyArt4、AssemblyArt56，并有LCS、AttachedTo和AttachmentOffset等装配属性。这修正了仅凭散件目录无法判断总装的局限。

| 源文件 / 总成 | 可确认的对应关系 |
|---|---|
| AssemblyBase / BaseBot、BaseTop、BaseBearingFix、BaseBoxBody | 底座、支承和电控盒壳体 |
| AssemblyArt1 / Art1Body、Art1Bot、Art1Top、Art1GearMotor | 第一转轴及其壳体/传动 |
| AssemblyArt2 / Art2BodyA、Art2BodyB、Art2BodyUnion、Art2SideCover | 第二轴及分体大臂壳体 |
| AssemblyArt3 / Art3Body、Art3Pulley、Art3Tensioner* | 第三轴/肘部传动与张紧 |
| AssemblyArt4 / Art4Body、Art4Bearing*、Art4MotorFix、Art4TransmissionColumn | 前臂roll及轴承/传动柱 |
| AssemblyArt56 / Art56MotorHolderA/B、Art56GearPlate、Art56Interface | 两个腕轴的联合总成，不能按文件数量误认为一个关节 |

FreeCAD实际读取Assembly.FCStd时，6个链接均能定位到本地子总成且返回非空Shape。对Art4和Art56直接查询聚合Shape得到非物理巨量包围盒（约±1e100），因此本轮不把这个聚合结果作为经过验证的实体碰撞模型，也未强行把它转换成我们的Master。原文件未修改。原始读取记录：`analysis/stage2/thor_assembly_check.json`。

抽查Art2BodyA特征树含Spreadsheet、Sketch、Body、Pad、Pocket、Datum与多种特征，适合借鉴“参数入口—草图/基准—实体特征—装配LCS”的组织方式。独立盖板、左右分壳、轴承固定件、走线空间与张紧件便于分工和维护。`step/`、`stl/`提供交换实体和打印网格，不等于所有文件都已形成完整单一实体。

官方装配文档入口：https://thor.angel-lm.com/documentation/assembly/ 。本轮尝试读取HTTPS、HTTP及documentation索引均超时；没有据此猜测网页中的装配步骤。现有源码总成与分件仍可继续参考。

商业项目不直接采用其原始壳体、步进电机、齿轮皮带、尺寸或装配几何。本项目的分段盒壳、轴承座、参数与脚本均新建；CC BY-SA条款保留在参考仓库，发布前按实际使用内容核查。

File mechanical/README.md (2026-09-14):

# arm_0 机械工程

正式主文件：[arm_0.FCStd](freecad/arm_0.FCStd)。参数：[arm_0_parameters.json](arm_0_parameters.json)。

请先看 [V3 拓扑与验证报告](docs/arm_0_v3_review.md)，再看 [装配顺序](docs/assembly_concept.md) 和 [待解决问题](docs/unresolved_issues.md)。

V3入口是 `scripts/build_arm_0.ps1`、`scripts/build_arm_0.py`、`scripts/SetArm0Pose.FCMacro`、`scripts/RebuildArm0.FCMacro`。所有操作方式见根目录README。

[legacy/v2](legacy/v2/README.md)为旧侧向错层模型，已SUPERSEDED。旧版参数、导出与报告保留用于比较。`Arm_v1_*`、`parameters.json`、`build.ps1`和对应第一阶段脚本为历史，不是当前重建入口。

PAROL6、CyberGear详细网格、Thor是参考，保持原名且不混入我们的主装配。

当前腕部为J5后置、J6前置的一体连接件方案，Flange已按用户确认从35改为86 mm。旧大框腕部快照见 [legacy/v3_box_wrist](legacy/v3_box_wrist/README.md)。

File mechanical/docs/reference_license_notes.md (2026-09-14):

# 第二阶段参考来源与许可证事实

记录日期2026-09-14。本文件只列来源、已看到的许可声明和待核对点，不作法律结论。

| 来源 | 当前本地版本 | 许可证事实 |
|---|---|---|
| PAROL6 | 3892e9c85c1f6d8041cda01c47c9db9d18b30ad8 | 根LICENSE为GPLv3；不能因README徽章alt残留MIT字样当作MIT |
| Thor | 286b081fe6f056d87c379b884781ef77ff6a0159 | 根LICENSE为CC BY-SA 4.0 |
| freezeLUO/CyberGear | db450fa86455ab1edd0c744fc6aef4e810573014 | 未找到LICENSE文件；README描述3D模型用途，但未给出完整明确的模型商业使用/改编/再分发许可条款 |
| 根目录用户SLDASM | 原文件保留 | 来源、版本与使用授权未知 |
| Y-arm | 尚未提供 | 未取得文件与许可证 |

仓库：[PAROL6](https://github.com/Source-Robotics/PAROL6-Desktop-robot-arm)、[Thor](https://github.com/AngelLM/Thor)、[CyberGear](https://github.com/freezeLUO/CyberGear)。

研究层：`PAROL6_reference_assembly.FCStd`包含上游网格，`CyberGear_Detail.FCStd`包含第三方定子和转子网格。这些是明确标记的参考文件，不混入我们的STEP装配。

独立重建层：arm_0中的底座、双侧肩架、盒形分段大臂、盖板、yoke、轴承座、紧固接口及腕部占位均由本项目脚本生成；没有缩放、改名或导入PAROL6/Thor原始零件。

CyberGear Envelope虽用基础实体独立生成，接口数值和孔中心来自该仓库的尺寸图/网格测量。独立编写脚本不自动等于来源权利问题已经解决；商业发布时仍需核查模型/数据的来源与可使用范围，必要时改用厂家正式提供或实测确认的接口资料。未知许可证不能直接写成“自由商用”。

本轮未重新许可参考仓库、未删除其LICENSE，也未将参考几何作为本项目原创零件发布。

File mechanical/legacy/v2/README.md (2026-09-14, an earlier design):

# V2 — SUPERSEDED

This is the archived side-lane prototype. The active design is ../../freecad/arm_0.FCStd.
Historical source/scripts and reports are snapshots; paths describe the original V2 layout, not a standalone build tree. To reproduce V2 exactly use Git commit fff31ea in a separate checkout. Do not use its poses or validation results for V3.

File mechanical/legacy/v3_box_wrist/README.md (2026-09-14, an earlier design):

# SUPERSEDED — arm_0 V3 box wrist

Snapshot before the user-authorized serial compact J5/J6 redesign. These files preserve the earlier 35 mm flange datum and box wrist for comparison. Not a standalone build tree. Current entry: ../../freecad/arm_0.FCStd.

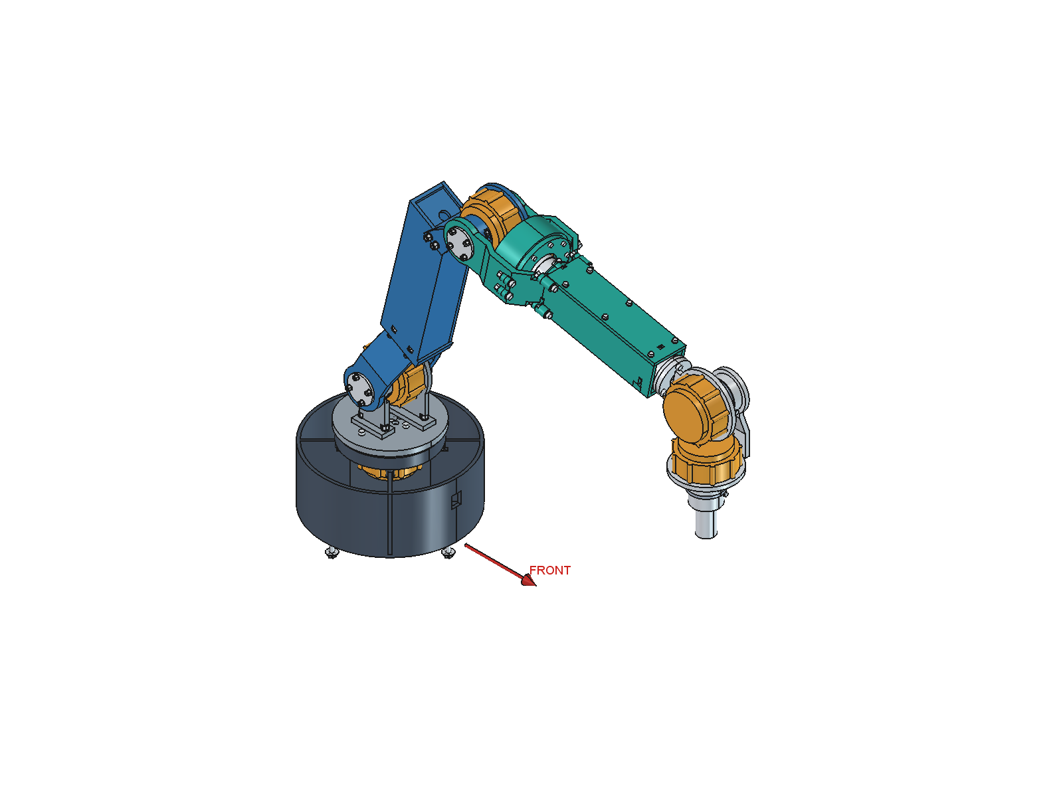
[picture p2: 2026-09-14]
mechanical/exports/arm_0_CAKE_APPROACH.png

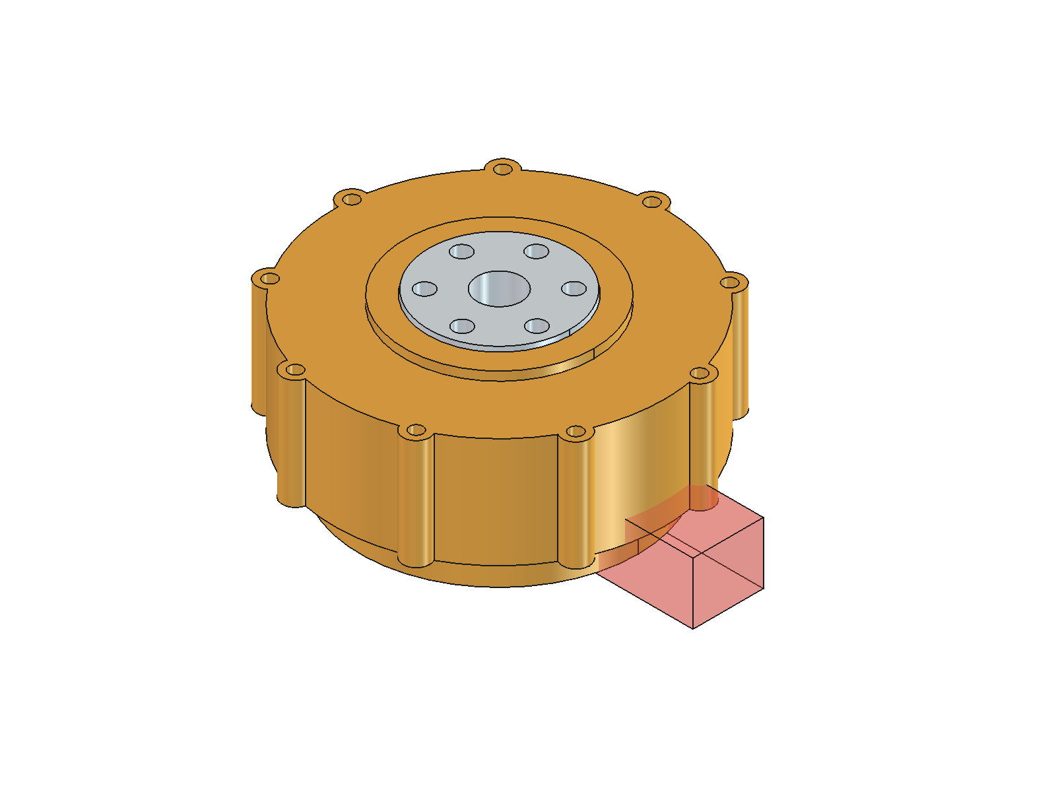
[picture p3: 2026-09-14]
mechanical/exports/CyberGear_Envelope.png

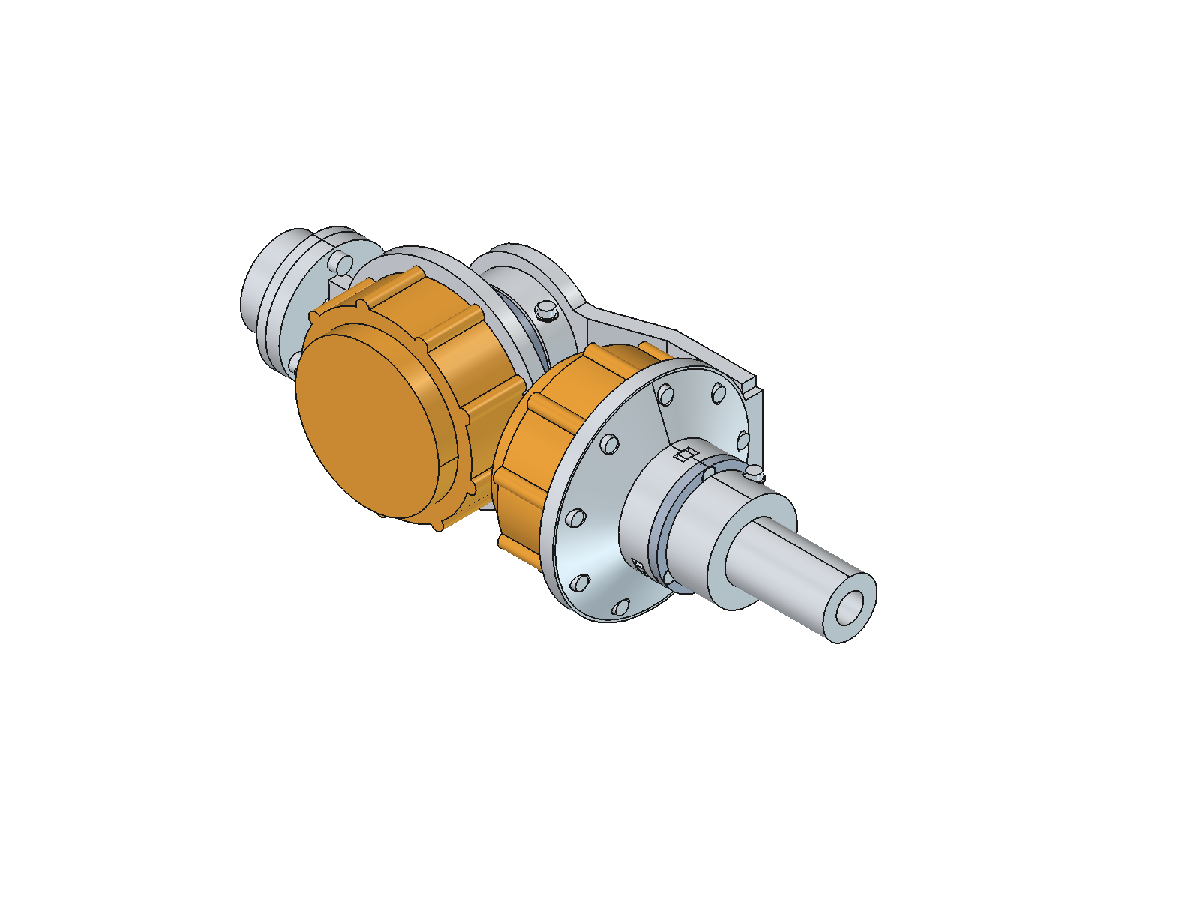
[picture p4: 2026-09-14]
mechanical/exports/arm_0_wrist.png

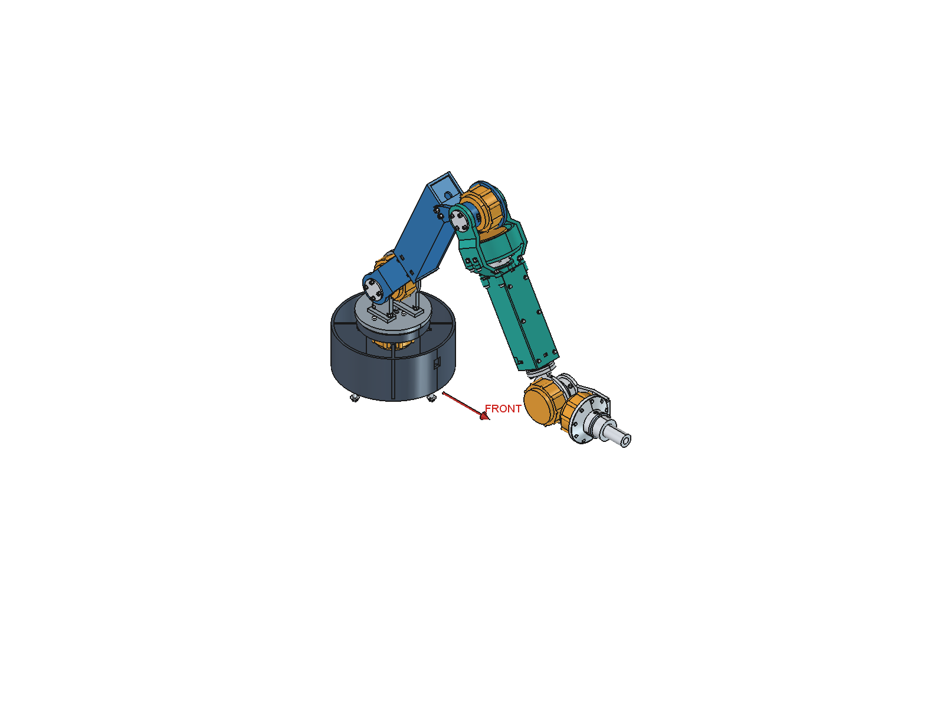
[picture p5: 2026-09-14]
mechanical/exports/arm_0_SAFE_UNFOLD.png

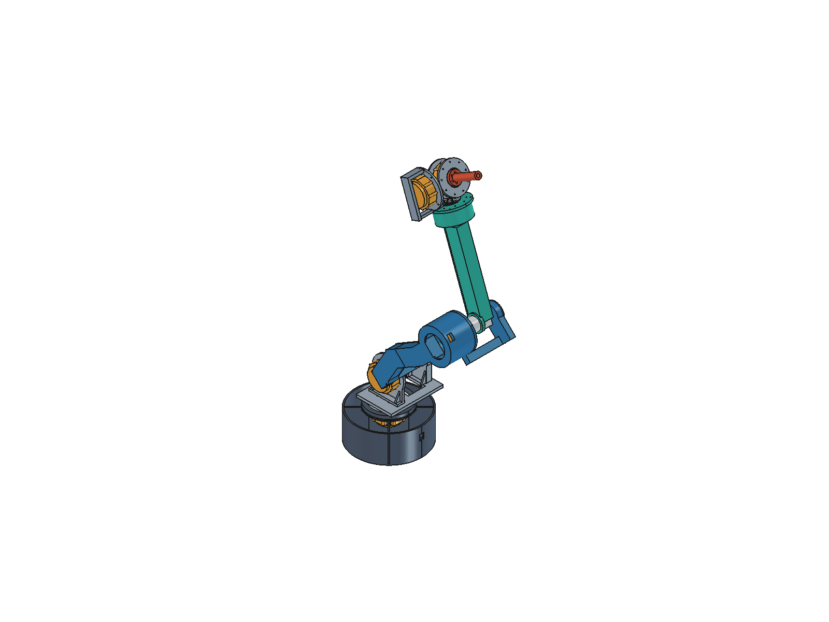
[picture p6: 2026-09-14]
mechanical/exports/Robot_HOME.png

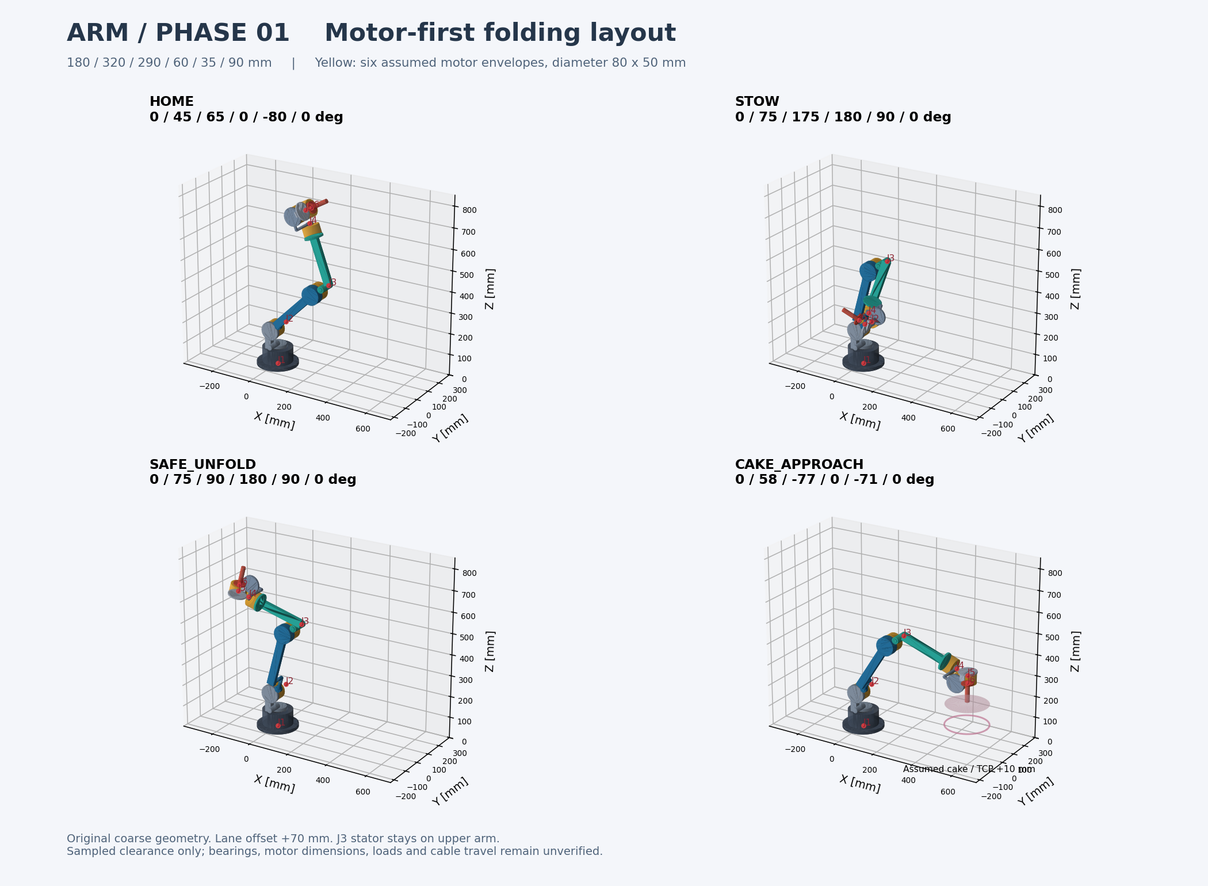
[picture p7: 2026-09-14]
mechanical/exports/layout_preview.png

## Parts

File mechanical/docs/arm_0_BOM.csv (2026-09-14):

Item_ID | Part_Name | Qty | Category | Material | Manufacturing_Method | Fastener_Size | Selected_Component | Status | Notes
B-001 | J1_BaseTray | 1 | printed | TBD polymer | FDM candidate |  | TBD | PROVISIONAL
B-002 | J1_MotorMount | 1 | printed | TBD polymer | FDM candidate |  | TBD | PROVISIONAL
B-003 | J1_BearingSeat | 1 | printed | TBD polymer | FDM candidate |  | TBD | PROVISIONAL
B-004 | J1_BearingPlaceholder | 1 | bearing | TBD metal | Purchased reference |  | TBD | PLACEHOLDER
B-005 | J1_OutputAdapter | 1 | metal | TBD metal | Machining TBD |  | TBD | PROVISIONAL
B-006 | J1_OutputHub | 1 | metal | TBD metal | Machining TBD |  | TBD | PROVISIONAL
B-007 | J1_RotatingPlatform | 1 | printed | TBD polymer | FDM candidate |  | TBD | PROVISIONAL
B-008 | J1_CyberGear_Motor | 1 | MOTOR_REFERENCE | Purchased motor | Purchased |  | CyberGear reference | HARDWARE_VERIFY | One motor assembly: J1_CyberGear_Stator + J1_CyberGear_Rotor reference shapes. Hardware verify.
B-010 | J2_CyberGear_Motor | 1 | MOTOR_REFERENCE | Purchased motor | Purchased |  | CyberGear reference | HARDWARE_VERIFY | One motor assembly: J2_CyberGear_Stator + J2_CyberGear_Rotor reference shapes. Hardware verify.
B-012 | J3_CyberGear_Motor | 1 | MOTOR_REFERENCE | Purchased motor | Purchased |  | CyberGear reference | HARDWARE_VERIFY | One motor assembly: J3_CyberGear_Stator + J3_CyberGear_Rotor reference shapes. Hardware verify.
B-014 | J4_CyberGear_Motor | 1 | MOTOR_REFERENCE | Purchased motor | Purchased |  | CyberGear reference | HARDWARE_VERIFY | One motor assembly: J4_CyberGear_Stator + J4_CyberGear_Rotor reference shapes. Hardware verify.
B-016 | J5_CyberGear_Motor | 1 | MOTOR_REFERENCE | Purchased motor | Purchased |  | CyberGear reference | HARDWARE_VERIFY | One motor assembly: J5_CyberGear_Stator + J5_CyberGear_Rotor reference shapes. Hardware verify.
B-018 | J6_CyberGear_Motor | 1 | MOTOR_REFERENCE | Purchased motor | Purchased |  | CyberGear reference | HARDWARE_VERIFY | One motor assembly: J6_CyberGear_Stator + J6_CyberGear_Rotor reference shapes. Hardware verify.
B-020 | J2_StatorPedestal | 1 | printed | TBD polymer | FDM candidate |  | TBD | PROVISIONAL | PROVISIONAL
B-021 | J2_OppositeBearingPedestal | 1 | printed | TBD polymer | FDM candidate |  | TBD | PROVISIONAL | PROVISIONAL
B-022 | J2_BearingRetainer | 1 | printed | TBD polymer | FDM candidate |  | TBD | PROVISIONAL | PROVISIONAL
B-023 | J2_BearingPlaceholder | 1 | bearing | TBD metal | Purchased reference |  | TBD | PLACEHOLDER | GEOMETRIC PLACEHOLDER 20x32x10
B-024 | J2_OutputCheek | 1 | printed | TBD polymer | FDM candidate |  | TBD | PROVISIONAL | PROVISIONAL
B-025 | J2_OppositeForkCheek | 1 | printed | TBD polymer | FDM candidate |  | TBD | PROVISIONAL | PROVISIONAL
B-026 | J2_ShortOutputHub | 1 | metal | TBD metal | Machining TBD |  | TBD | PROVISIONAL | PROVISIONAL
B-027 | J2_ShortBearingStub | 1 | metal | TBD metal | Machining TBD |  | TBD | PROVISIONAL | PROVISIONAL
B-028 | Upper_CentralBox | 1 | printed | TBD polymer | FDM candidate |  | TBD | PROVISIONAL | PROVISIONAL
B-029 | Upper_RemovableCover | 1 | printed | TBD polymer | FDM candidate |  | TBD | PROVISIONAL | PROVISIONAL
B-030 | J3_StatorMount | 1 | printed | TBD polymer | FDM candidate |  | TBD | PROVISIONAL | PROVISIONAL
B-031 | J3_FixedBearingSupport | 1 | printed | TBD polymer | FDM candidate |  | TBD | PROVISIONAL | PROVISIONAL
B-032 | J3_BearingRetainer | 1 | printed | TBD polymer | FDM candidate |  | TBD | PROVISIONAL | PROVISIONAL
B-033 | J3_BearingPlaceholder | 1 | bearing | TBD metal | Purchased reference |  | TBD | PLACEHOLDER | GEOMETRIC PLACEHOLDER 20x32x10
B-034 | J3_OutputForkCheek | 1 | printed | TBD polymer | FDM candidate |  | TBD | PROVISIONAL | PROVISIONAL
B-035 | J3_OppositeForkCheek | 1 | printed | TBD polymer | FDM candidate |  | TBD | PROVISIONAL | PROVISIONAL
B-036 | J3_ShortOutputHub | 1 | metal | TBD metal | Machining TBD |  | TBD | PROVISIONAL | PROVISIONAL
B-037 | J3_ShortBearingStub | 1 | metal | TBD metal | Machining TBD |  | TBD | PROVISIONAL | PROVISIONAL
B-038 | J4_ProximalStatorHousing | 1 | printed | TBD polymer | FDM candidate |  | TBD | PROVISIONAL | PROVISIONAL
B-039 | J4_ProximalBearingRetainer | 1 | printed | TBD polymer | FDM candidate |  | TBD | PROVISIONAL | PROVISIONAL
B-040 | J4_ProximalBearingHousing | 1 | printed | TBD polymer | FDM candidate |  | TBD | PROVISIONAL | PROVISIONAL
B-041 | J4_ProximalBearing | 1 | bearing | TBD metal | Purchased reference |  | TBD | PLACEHOLDER | GEOMETRIC PLACEHOLDER 22.2x32x10
B-042 | J4_DistalBearingRetainer | 1 | printed | TBD polymer | FDM candidate |  | TBD | PROVISIONAL | PROVISIONAL
B-043 | J4_DistalBearingHousing | 1 | printed | TBD polymer | FDM candidate |  | TBD | PROVISIONAL | PROVISIONAL
B-044 | J4_DistalBearing | 1 | bearing | TBD metal | Purchased reference |  | TBD | PLACEHOLDER | GEOMETRIC PLACEHOLDER 22.2x32x10
B-045 | Forearm_CentralBox | 1 | printed | TBD polymer | FDM candidate |  | TBD | PROVISIONAL | PROVISIONAL
B-046 | Forearm_RemovableCover | 1 | printed | TBD polymer | FDM candidate |  | TBD | PROVISIONAL | PROVISIONAL
B-047 | J4_MotorOutputAdapter | 1 | metal | TBD metal | Machining TBD |  | TBD | PROVISIONAL | PROVISIONAL
B-048 | J4_TorqueTube | 1 | metal | TBD metal | Machining TBD |  | TBD | PROVISIONAL | PROVISIONAL
B-049 | J4_DistalOutputHub | 1 | metal | TBD metal | Machining TBD |  | TBD | PROVISIONAL | PROVISIONAL
B-050 | J5_CompactStatorSupport | 1 | metal | TBD metal | Machining TBD |  | TBD | PROVISIONAL | PROVISIONAL compact wrist; hardware and loads unverified
B-051 | J5_RemovableBearingSeat | 1 | metal | TBD metal | Machining TBD |  | TBD | PROVISIONAL | PROVISIONAL compact wrist; hardware and loads unverified
B-052 | J5_OutputSupportBearing | 1 | bearing | TBD metal | Purchased reference |  | TBD | PLACEHOLDER | GEOMETRIC PLACEHOLDER 15x32x9; single outboard support plus motor internal bearings
B-053 | J5_BearingRetainer | 1 | printed | TBD polymer | FDM candidate |  | TBD | PROVISIONAL | PROVISIONAL compact wrist; hardware and loads unverified
B-054 | J5_ShortOutputHub | 1 | metal | TBD metal | Machining TBD |  | TBD | PROVISIONAL | PROVISIONAL compact wrist; hardware and loads unverified
B-055 | J6_OnePieceConnector | 1 | metal | TBD metal | Machining TBD |  | TBD | PROVISIONAL | ONE-PIECE metal flange/web/ring connector; process, stiffness and preload unverified
B-056 | J6_OutputBearing | 1 | bearing | TBD metal | Purchased reference |  | TBD | PLACEHOLDER | GEOMETRIC PLACEHOLDER 15x32x9
B-057 | J6_BearingRetainer | 1 | printed | TBD polymer | FDM candidate |  | TBD | PROVISIONAL | PROVISIONAL compact wrist; hardware and loads unverified
B-058 | J6_ShortOutputHub | 1 | metal | TBD metal | Machining TBD |  | TBD | PROVISIONAL | Metal output neck installed with motor from rear; support seat remains on connector
B-059 | J6_RemovableToolAdapter | 1 | metal | TBD metal | Machining TBD |  | TBD | PROVISIONAL | Removable split-clamp tool adapter, 13 mm engagement; axial retention and torque capacity provisional
B-060 | M3_Bolt | 109 | FASTENER | Steel TBD | Purchased | M3 | TBD supplier | HARDWARE_VERIFY | Installed envelopes; bolt length TBD; each instance traced by fastener_schedule; washer envelope is provisional
B-061 | M3_HeadWasher | 29 | FASTENER | Steel TBD | Purchased | M3 | TBD supplier | HARDWARE_VERIFY | Installed envelopes; bolt length TBD; each instance traced by fastener_schedule; washer envelope is provisional
B-062 | M3_LockNut | 51 | FASTENER | Steel TBD | Purchased | M3 | TBD supplier | HARDWARE_VERIFY | Installed envelopes; bolt length TBD; each instance traced by fastener_schedule; washer envelope is provisional
B-063 | M3_NutWasher | 29 | FASTENER | Steel TBD | Purchased | M3 | TBD supplier | HARDWARE_VERIFY | Installed envelopes; bolt length TBD; each instance traced by fastener_schedule; washer envelope is provisional
B-064 | M4_Bolt | 65 | FASTENER | Steel TBD | Purchased | M4 | TBD supplier | HARDWARE_VERIFY | Installed envelopes; bolt length TBD; each instance traced by fastener_schedule; washer envelope is provisional
B-065 | M4_HeadWasher | 20 | FASTENER | Steel TBD | Purchased | M4 | TBD supplier | HARDWARE_VERIFY | Installed envelopes; bolt length TBD; each instance traced by fastener_schedule; washer envelope is provisional
B-066 | M4_LockNut | 22 | FASTENER | Steel TBD | Purchased | M4 | TBD supplier | HARDWARE_VERIFY | Installed envelopes; bolt length TBD; each instance traced by fastener_schedule; washer envelope is provisional
B-067 | M4_NutWasher | 20 | FASTENER | Steel TBD | Purchased | M4 | TBD supplier | HARDWARE_VERIFY | Installed envelopes; bolt length TBD; each instance traced by fastener_schedule; washer envelope is provisional
B-068 | M5_Bolt | 4 | FASTENER | Steel TBD | Purchased | M5 | TBD supplier | HARDWARE_VERIFY | Installed envelopes; bolt length TBD; each instance traced by fastener_schedule; washer envelope is provisional
B-069 | M5_HeadWasher | 4 | FASTENER | Steel TBD | Purchased | M5 | TBD supplier | HARDWARE_VERIFY | Installed envelopes; bolt length TBD; each instance traced by fastener_schedule; washer envelope is provisional
B-070 | M5_LockNut | 4 | FASTENER | Steel TBD | Purchased | M5 | TBD supplier | HARDWARE_VERIFY | Installed envelopes; bolt length TBD; each instance traced by fastener_schedule; washer envelope is provisional
B-071 | M5_NutWasher | 4 | FASTENER | Steel TBD | Purchased | M5 | TBD supplier | HARDWARE_VERIFY | Installed envelopes; bolt length TBD; each instance traced by fastener_schedule; washer envelope is provisional
B-072 | FourWayNutBlock | 0 | CATALOG | Metal TBD | Purchased | M4 | 2-M4*8-H10*22 | PROVISIONAL / IMAGE SPECIFICATION | User will purchase fifth row. 90 degree independent-plate connections only. Current interfaces are parallel stacks or integral ribs, installed0. Hole depths TBD.

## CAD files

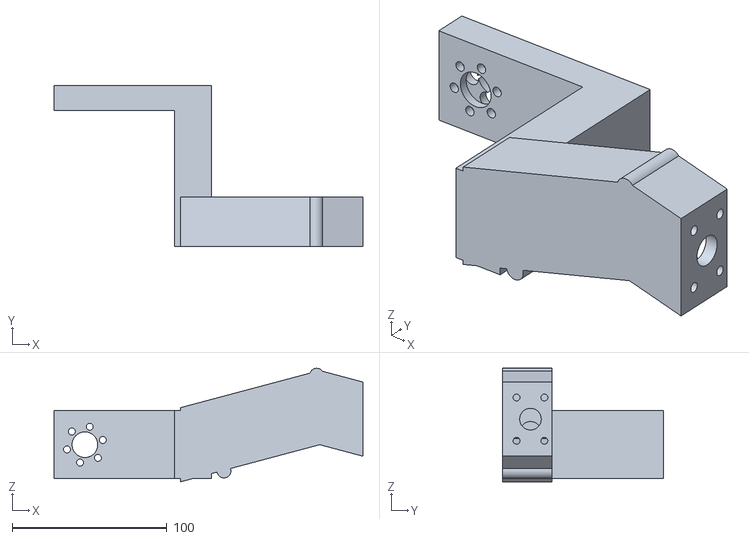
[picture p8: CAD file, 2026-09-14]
mechanical/exports/print_fit/Upper_MainShell_Proximal.stl
200.0 x 104.0 x 73.5

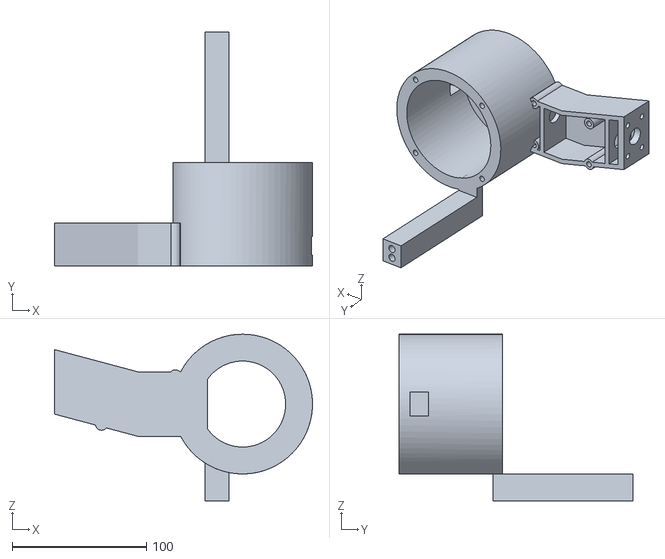
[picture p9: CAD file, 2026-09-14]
mechanical/exports/print_fit/Upper_MainShell_Distal.stl
192.0 x 174.0 x 124.0

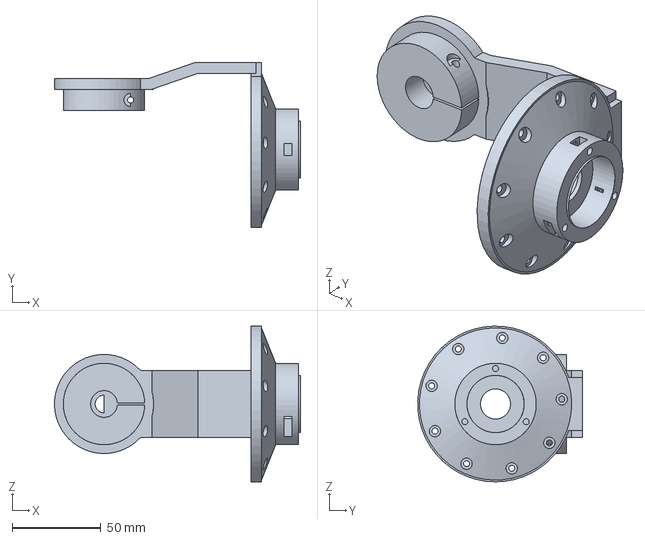
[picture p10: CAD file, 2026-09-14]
mechanical/exports/arm_0_J6_OnePieceConnector.step
139.0 x 92.9 x 88.0 mm

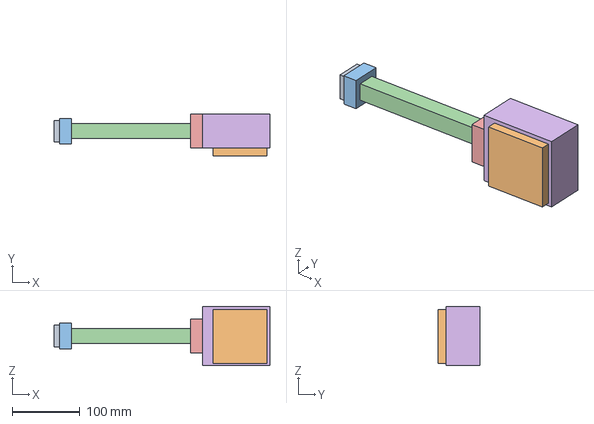
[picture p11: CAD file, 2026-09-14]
mechanical/exports/envelope/arm_0_roll_envelope.step
320.0 x 61.5 x 88.0 mm

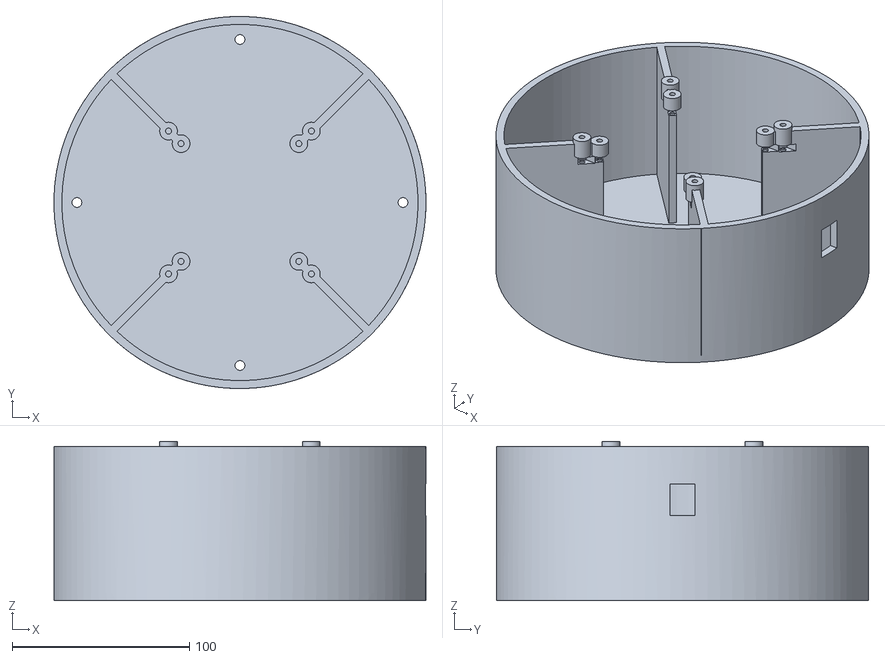
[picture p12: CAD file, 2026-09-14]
mechanical/exports/print_fit/J1_BaseTray.stl
209.9 x 210.0 x 90.0

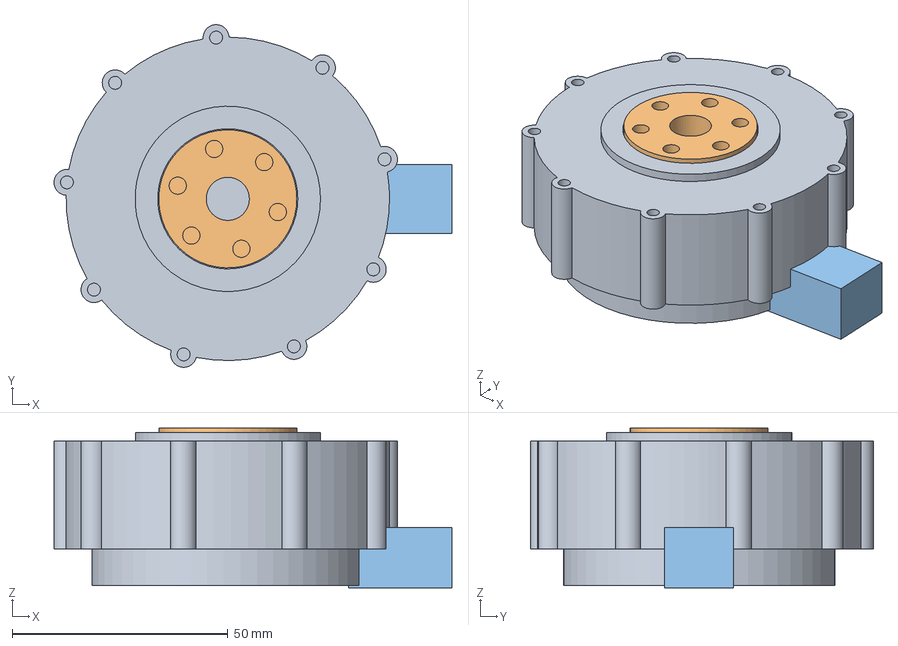
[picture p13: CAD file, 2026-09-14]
mechanical/freecad/CyberGear_Envelope.FCStd
92.3 x 79.5 x 37.0 mm
CyberGear_stator
CyberGear_rotor
CyberGear_cable_reserve

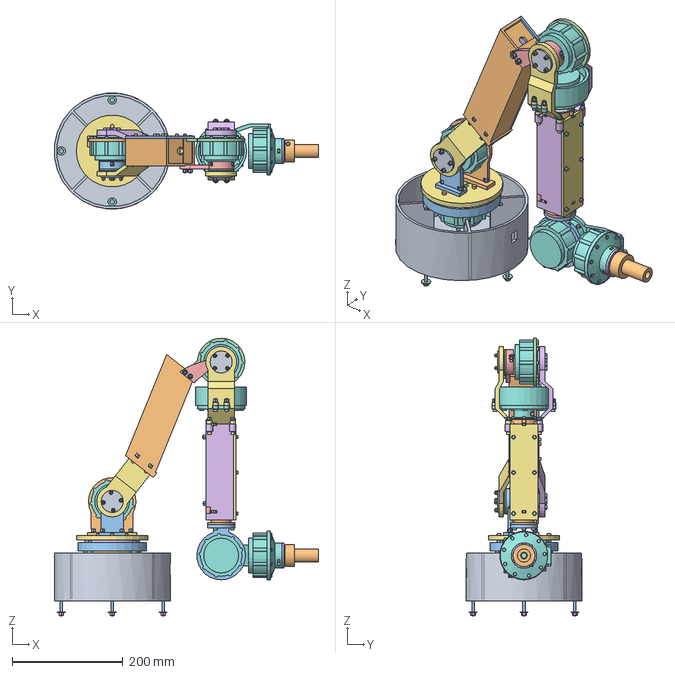
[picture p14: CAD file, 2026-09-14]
mechanical/exports/arm_0.step
477.4 x 209.6 x 501.9 mm

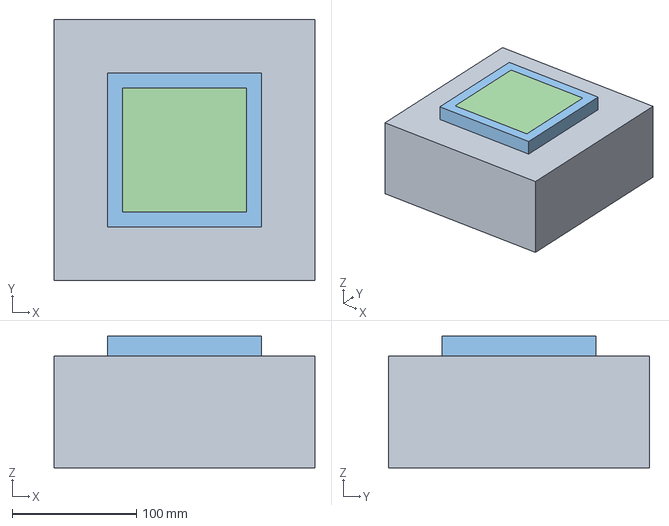
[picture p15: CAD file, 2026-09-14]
mechanical/exports/envelope/arm_0_base_envelope.step
209.9 x 210.0 x 106.0 mm

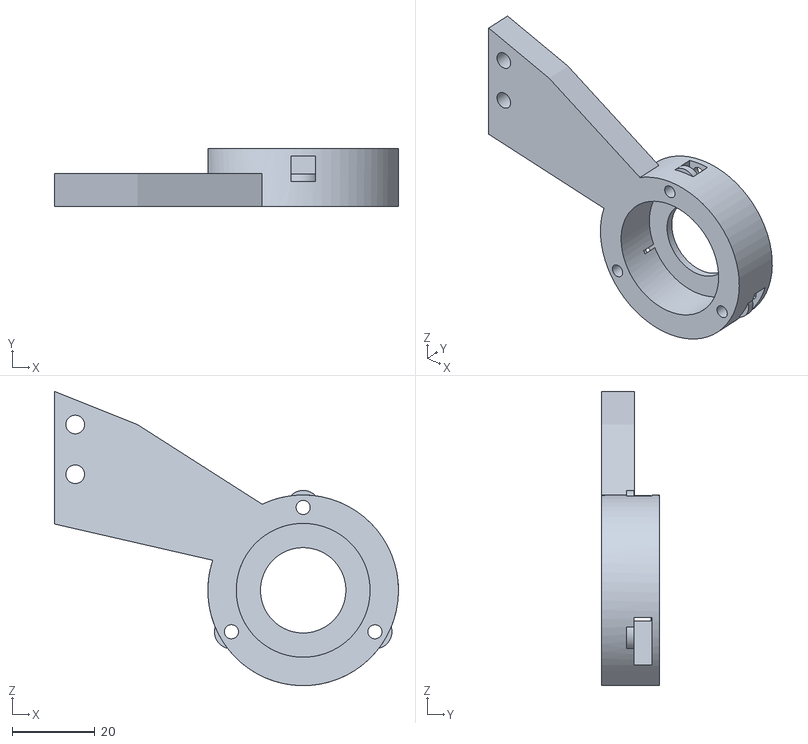
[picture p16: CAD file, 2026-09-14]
mechanical/exports/print_fit/J3_FixedBearingSupport.stl
83.0 x 14.0 x 71.0

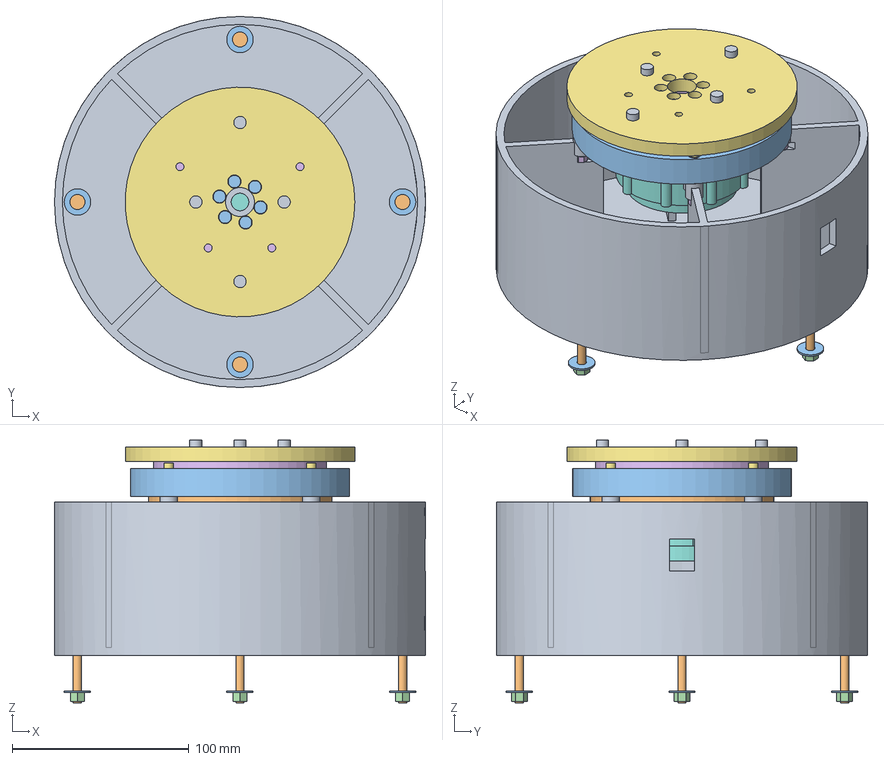
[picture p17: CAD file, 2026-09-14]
mechanical/exports/arm_0_J1.step
210.0 x 210.0 x 148.8 mm

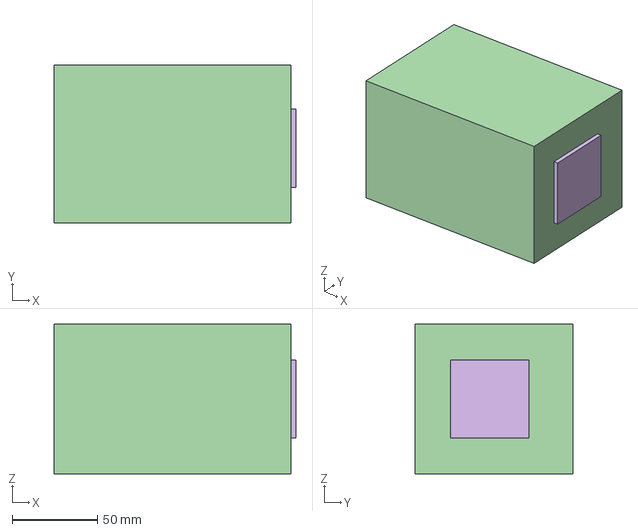
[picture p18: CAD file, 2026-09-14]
mechanical/exports/envelope/arm_0_pitch_envelope.step
142.0 x 93.0 x 88.0 mm

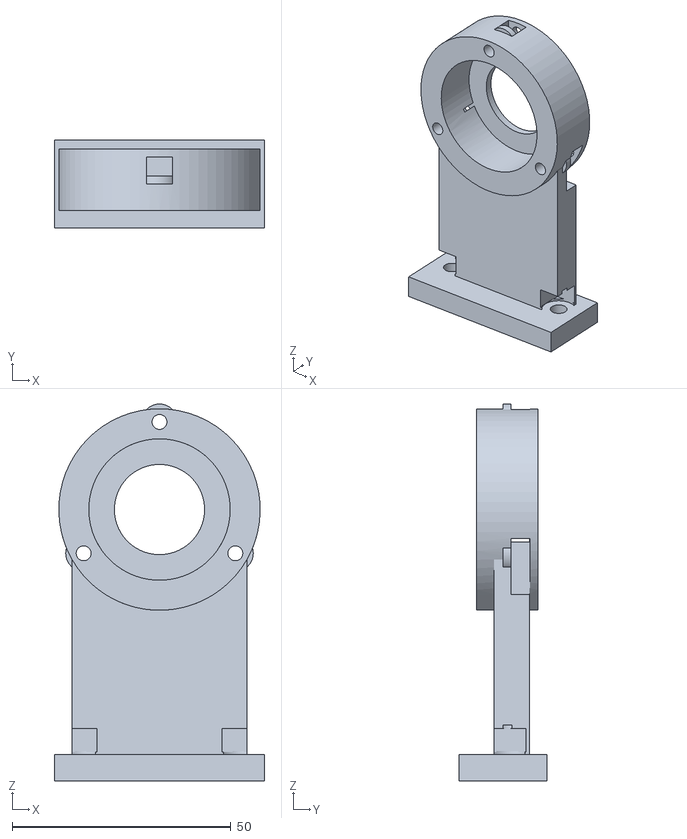
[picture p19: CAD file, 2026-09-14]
mechanical/exports/print_fit/J2_OppositeBearingPedestal.stl
48.0 x 20.0 x 86.1

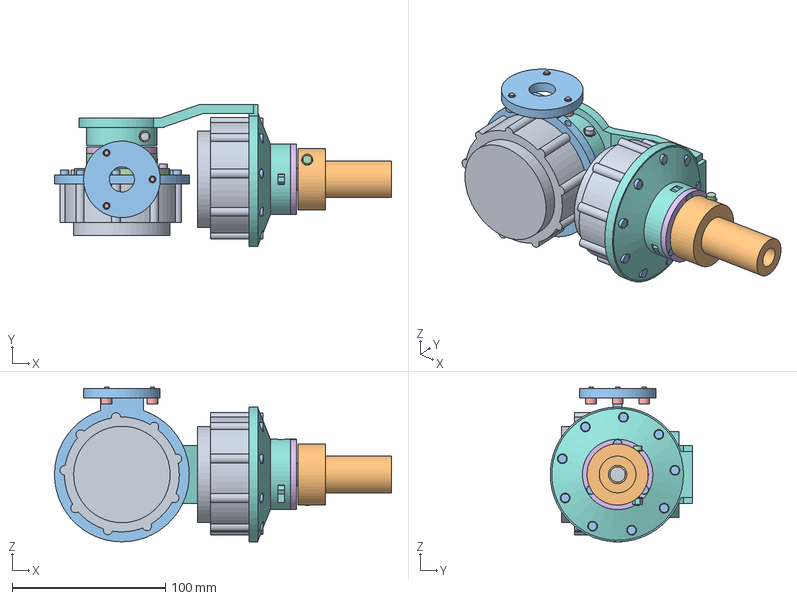
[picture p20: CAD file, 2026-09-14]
mechanical/exports/arm_0_wrist.step
220.0 x 92.9 x 101.0 mm

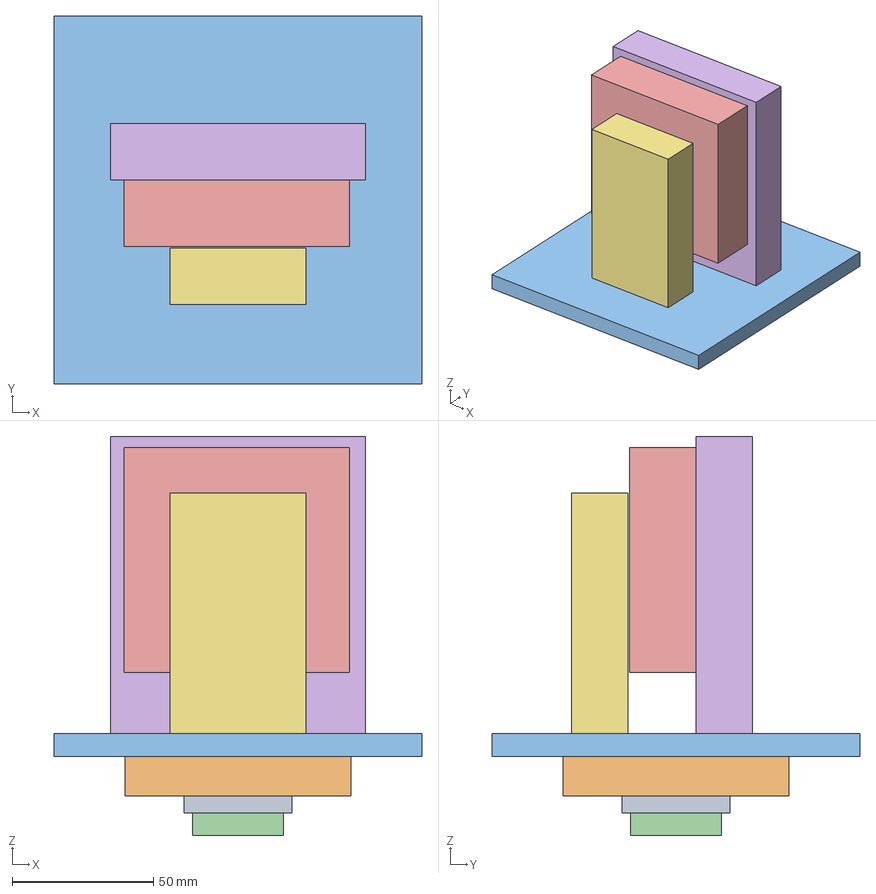
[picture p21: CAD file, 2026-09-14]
mechanical/exports/envelope/arm_0_yaw_envelope.step
130.0 x 129.9 x 141.0 mm

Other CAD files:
mechanical/exports/print_fit/J5_BearingRetainer.stl
mechanical/exports/arm_0_J3.step
mechanical/exports/envelope/arm_0_upper_envelope.step
mechanical/exports/print_fit/Upper_CentralBox.stl
mechanical/exports/Arm_v1_CAKE_APPROACH.step
mechanical/exports/Arm_v1_EXTENDED.step
mechanical/exports/Arm_v1_HOME.step
mechanical/exports/Arm_v1_SAFE_UNFOLD.step
mechanical/exports/Arm_v1_STOW.step
mechanical/exports/J1_base.step
mechanical/exports/J2_shoulder.step
mechanical/exports/J3_upper_elbow.step
mechanical/exports/Robot_Master_coarse.step
mechanical/exports/arm_0_J2.step
mechanical/exports/envelope/arm_0_fore_envelope.step
mechanical/exports/envelope/arm_0_tool_envelope.step
mechanical/exports/envelope/base_envelope.step
mechanical/exports/envelope/forearm_envelope.step
mechanical/exports/envelope/shoulder_envelope.step
mechanical/exports/envelope/tool_envelope.step
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

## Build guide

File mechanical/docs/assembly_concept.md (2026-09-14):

# arm_0 Prototype 0 冻结前装配审查

这是一份首次审图用装配顺序，不能代替加工图和实物试装。当前尺寸链180/320/290/60/86/90 mm，两根主体盒梁中心Y=0；冻结姿态不变。接口编号、螺钉数量、方向、接收端和拆卸前置条件见fastener_schedule.csv；数值验证见assembly_validation.json。所有螺钉采购长度TBD。

## 标准件和接收端

电机固定为9-M3通孔拧入CyberGear金属螺纹，输出为6-M4通孔拧入转子；不得把包络中的1 mm螺纹占用当作最终有效啮合长度。打印件主要接口使用M4通孔、垫圈和防松螺母，盖板/压盖局部使用M3可更换金属螺母。金属夹紧件可用待核定的机加工螺纹。热熔嵌件、塑料直接攻牙、自攻螺钉、胶粘承力均不作为正式连接。

FourWayNutBlock按用户指定图片第五行2-M4×8-H10×22选为候选，仅用于两块独立板材的90°连接。本轮叉片端面和安装耳等属于平行夹层，使用螺钉加防松螺母；盒梁直角筋为整体打印，不增加虚构的可拆接口。该连接块当前安装数量0，标称22×10×10 mm、两对孔距8 mm、L3=5 mm，孔深和内部交孔待实测。

## 顺序与维修

1. J1：底座开口时放入可更换金属螺母；安装电机板与9-M3定子螺钉，再装支承座和轴承占位。装6-M4金属输出hub后安装回转平台。J2支撑的M4螺钉由平台下侧凹座向上插入、螺母在支撑脚上侧；在回转部装到底座前完成此子装配。底座四个Ø5.5孔采用M5、加大垫圈与防松螺母固定实验台，台厚未知。
2. J2：在双叉未合拢时安装电机、对侧轴承与压盖；安装输出侧6-M4；对侧叉片与短轴颈先用4-M3在台面预装成一组，再沿轴向插入父轴承。维修时保持这4-M3不动，拆端框后将叉片/短轴颈整组拔出，取出后才访问其内侧螺钉头。压盖先于这组零件安装。两片叉在大臂端框处用4-M4通孔与防松螺母连接。盖板最后安装，螺母槽从开放侧装入。
3. J3：前支撑与对侧支撑通过两颗M4跨越大臂内部隔框，盖板不承担唯一固定作用。安装电机、轴承/压盖，再装小臂两片子叉、输出hub与预装好的对侧叉片/短轴颈组；短轴颈4-M3同J2在台面预装，不能在包住父关节后才拧内侧螺钉。在J4近端电机与壳体安装完成后再合拢叉片、固定小臂盒梁。
4. J4：壳体9-M3、输出适配器6-M4先于扭矩管安装。两端轴承与压盖先装至独立座；局部安装耳以M4固定到底板；远端两颗M4在局部平面直接落座，不装垫圈，以免垫圈边缘碰到压盖，局部压应力须在首件审查中核定。此时扭矩管尚未穿入，才能从上方操作安装耳螺钉。穿入OD22/ID17、长192 mm金属管，安装两端夹紧接头和腕部。近端接头M3防松螺母；远端接头下半金属螺纹避免螺母占用角部线槽。有效螺纹、薄壁局部和夹紧传扭仍待工程确认。盖板最后安装。
5. J5：支架固定到J4远端hub，轴承座拆下时完成9-M3定子和6-M4输出螺钉。然后安装可拆轴承座、轴承、压盖，最后套入并夹紧J6一体金属连接件。标准螺钉头使用局部凹座，不能把压盖与连接件预先封闭后再尝试安装输出螺钉。
6. J6：预装电机与短输出轴，再装输出轴承和压盖，最后夹紧独立工具接头。维修从工具端反向拆卸，先松工具接头，再拆压盖/轴承和电机，随后释放J5连接件及其支承。

维修以卸载、拆开的刚体子装配为检查状态；每个接口的额外拆件清单由工具包络检查给出。紧固件、螺母与垫圈参与整机运动包络检查，内六角工具和螺母退出包络只用于静态维修检查。35 mm为工具进入长度预算，不是腕距。螺母更换需先取出对应螺钉和活动垫圈。

## 审图重点

核对全部金属螺纹有效深度、螺钉长度、锁紧螺母完全啮合、螺钉头凹座的剩余壁厚、M3盖板螺母槽的打印质量。局部避空可能降低刚度；实体有效和几何不相交不证明承载合格。打印件只作为静态试装候选，轴承和电机接口均需实物核对。拆装包络不覆盖工具弯头、手掌和实际扭矩扳手外形。检查中的脱开刚体按上述子装配顺序执行，不表示可在整机封闭状态下访问所有螺钉。

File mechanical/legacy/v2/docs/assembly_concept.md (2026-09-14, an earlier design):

# J1～J3 工程粗模装配顺序

所有紧固件、嵌件、配合公差和轴承选型仍为PROVISIONAL。文件用于静态试装和打印结构迭代；不能据此直接释放带载电动样机。

## 制造参数及分件

主体壳壁4 mm；盒体筋4 mm；盖板4 mm；电机固定板6 mm；局部连接平台8 mm。不是把整个底座或连杆做成实心块。J1开口底座外径210 mm，顶面可直接装入电机；有径向筋、两组带嵌件预孔的安装柱和线缆出口。

大臂用24 mm浅弯偏置/90 mm过渡（约14.93°），J2→J3轴线代表点仍为320 mm。实体沿X=180 mm分为两段，接缝两侧各6 mm局部端板，用4个M4通孔连接，中央14 mm过线孔；大臂盖板单独拆卸。未改变关节运动学来凑折线外形。

| 项目 | 当前建模值 | 状态 |
|---|---|---|
| M3 / M4 / M5通孔 | 3.4 / 4.5 / 5.5 mm | PROVISIONAL打印补偿 |
| M3嵌件预孔 | Ø4.6，深5 mm | 须按选定嵌件厂家规格重定 |
| M4嵌件预孔 | Ø6.2，深8 mm | 同上，未指定品牌 |
| J2/J3轴承占位 | 内径20、外径42、宽12 mm | 未定型号、精度/额定载荷 |
| 轴承座 | Ø42.2止口，12 mm深；后肩/压盖 | 偏差并非最终公差配合 |
| 对侧轴颈 | Ø19.8；中间轴段Ø16 | 金属加工占位，非最终轴设计 |
| J1回转支承占位 | ID80 / OD100 / 宽10 mm | 尚未指定轴承类型/预紧/载荷 |
| J1轴承座定位 | 对Ø104安装板外周预留约0.15 mm径向间隙 | 原型定位概念 |

13个J1～J3打印候选件的STL已导出，均为单一有效实体且重读为封闭网格；尺寸清单在 `analysis/stage2/deliverable_checks.json`。这些是在零件局部坐标下导出的STL，负坐标正常，切片时需放到平台上。

最长的两段大臂已拆开；包围盒可用于核对机型工作范围，但包围盒容纳不证明最优打印方向、支撑、翘曲或强度。220 mm级设备还需给裙边/支撑留余量。金属轴、轴承和输出转接件不列入打印清单。

## J1

1. 先处理底座锚固孔、M3嵌件预孔与走线窗口；用校准试块核对嵌件，不能把未确认预孔直接当成压入公差。
2. 电机从开口上方放入。先将电机前面9-M3接口固定到可拆电机板：螺钉从板的输出侧向电机旋入，中央Ø44避开Ø43固定止口及输出盘。
3. 将电机连同安装板落到底座4个安装柱，用外圈4-M3固定。端子置于后侧预留方向，线缆通过底座侧窗口；实际插头角度待核对。
4. 装J1支承座，底部止口围住安装板外周，另4-M3从座外圈拧入底座较高安装柱；支承放入带肩的座中。
5. 输出转接件固定在转子，输出hub/skirt与独立支承配合，再装上部平台。平台与hub间为4-M4通孔；下侧留出螺母/工具访问空间。
6. 肩架安装完成前仍可从上方拆出电机和支承。底座四个M5锚固孔用于实验台固定，不代表已验证抗倾覆。

仍需确认：J1轴承类型与真实内外圈、轴向压紧/预紧、输出转接件与hub的最终锁紧。当前相接的金属转接面不应当成已设计完成的抗松脱连接。

## J2

1. 左侧电机板与右侧轴承板均为独立件，下部有安装脚/筋，形成跨肩支承；保留右板未装，避免封闭后无法放入大臂输出件。
2. J2电机从左板后侧（-Y）贴合前固定面，9个M3螺钉从+Y固定。先在台面上装好电机板，便于访问螺钉。
3. 把输出转接件与大臂近端盒接口连接；六个输出孔采用实测模型坐标和M4通孔，后续按实际叠层厚度选择螺钉，进入转子不得超过图示有效深度6 mm。
4. 近端盒预留螺钉通孔及较大工具孔。装入金属贯穿轴，再把右侧轴承压入有肩座；从+Y装轴承板套住对侧轴颈。
5. 固定右板到底座平台，装轴承压盖。右板脚的M4嵌件从安装前的底面装入，平台螺钉从下方拧入；左板脚用通孔紧固。
6. 静态手动转动，检查轴承同轴性、轴向卡紧、输出盘偏摆和线缆。拆卸反向执行，不依赖单侧薄悬臂作为唯一支承。

仍需确认：贯穿轴的键/夹紧/止退、压盖外圈/内圈受力区域、轴承预紧、真实电机允许外载。粗模没有把这些配合当作已完成的机械连接验证。

## J3及大臂

1. 先通过大臂两段的4-M4接缝组装盒壳；中间过线孔保持通畅。盖板暂不装，检查螺母/扳手是否能从开放侧进入。
2. J3定子安装板单独与电机前9-M3孔连接。J3对侧轴承板是**可拆件**，此时保持拆下。
3. 电机从肘壳正面（+Y）放入，后部电子区穿过壳后部Ø64孔；安装板用外圈4-M3固定到肘壳预孔。J3定子从此固定在大臂远端壳体上。
4. 在输出端安装一体式金属小臂输出hub：固定盘、短管段和小臂根部连接块为同一设计件，设有沿轴向贯通的六个M4螺钉访问通道，孔位沿用输出接口。必须复核长螺钉可得性、啮合深度和工具路径；不是已经指定了最终螺钉长度。
5. 安装贯穿轴与小臂根部。小臂侧壁有轴孔、输出螺钉头访问孔，盖板有轴夹紧螺钉访问位置。当前夹紧孔只作为金属加工概念，真实轴槽/锁紧方式需定型。
6. 将轴承装入可拆对侧板，套到输出轴颈，再从+Y用2个M4紧固在yoke端面，最后装M3轴承压盖。先拆此板即可再次访问输出长螺钉和电机，不需要破坏大臂壳体。
7. 核对小臂在y=+70 mm侧向折回的空间，然后装大臂盖板。J3定子不随小臂转动，只有输出hub/轴/根部与小臂一起动。

本版父支架横向仍较宽：大臂主壳中心-62 mm、小臂中心+70 mm，差132 mm；对侧支承在约+110 mm。它实现了侧向嵌套与可拆卸性，但还不是最紧凑宽度。J3局部托臂没有跨越小臂主要折回路径，后续可在真实电机/轴承确定后继续缩短轴向堆叠。

## 释放制造前的边界

可立即用于：查看装配、核对模型和实物、切片/静态打印试装、研究安装工具路径。

必须继续完成：真实电机孔位/止口验证；嵌件与轴承选型；金属件锁紧与加工图；打印方向/材料/层间受力；轴承同轴公差；静力/挠度与热；J2扭矩方案；线束与硬限位。螺纹只用孔与预孔表示，没有承诺最终配合与负载。

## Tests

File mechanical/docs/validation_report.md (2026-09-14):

# v1 实际验证结果

日期：2026-09-14。FreeCAD 1.1.3 / 自带 Python 3.11，OCCT 实体几何。
当前参数来自 `mechanical/parameters.json`；导出清单见 `analysis/export_checks.json`。

## 几何和数据一致性

- HOME、STOW、SAFE_UNFOLD、EXTENDED、CAKE_APPROACH 共 5 个 FCStd 与 5 个 STEP。
- 每份 36 个机械实体/接口对象，其中恰好 6 个 motor；另有 6 根轴线和主骨架折线，不进入 STEP。
- 重新打开 FCStd，所有机械实体 isValid；重新导入 STEP，均为 36 个有效 solids。导出前后体积差小于 0.000001 mm³。它们是多零件交换实体，不是焊接成一个整体的制造模型。
- 改变 J3 而固定 J1/J2，J3 电机质心与姿态不变；主骨架320/290/60/35中心距断言通过。
- 彩色视图和默认相机已通过 FreeCAD GUI 保存；主骨架默认隐藏，可在树中展开并显示。

## 干涉算法范围

检测全部电机两两组合以及不同刚体间零件组合。相同刚体的结构件之间允许有连接体积重叠；不以“相邻关节”为理由跳过跨刚体干涉。先用包围盒筛除远离对象，再用 `distToShape` 和 `common().Volume` 精查。

相交体积大于0.01 mm³记为穿透。小于5 mm的正间隙另列；零距离面接触不等同于穿透。没有把接触/微小间隙认定为制造公差合格。电机圆柱是整体外包络，内部转子、轴承滚动体和线缆没有建模。

4个主姿态均无检测到的跨刚体穿透，最低实体Z=0（底座贴桌面），motor间最小距离10 mm。CAKE_APPROACH也通过自碰撞检测。肩/肘/腕的部分输出接口仍存在2…4 mm间隙或面接触，详见 `analysis/pose_checks.json`，后续必须真实装配审核。

## J3 深折叠对照

固定 J1=0、J2=75、J6=0，对 J3=90…200°，步长2°，每组56个样本：

| 腕姿态 | 有穿透样本 | 首个失败采样点 | motor最小间距 |
|---|---:|---|---:|
| 朝内 J4=0、J5=-90 | 13 / 56 | J3=168°，Motor_J2—Motor_J5 及 J5_Mount 干涉 | 0 mm |
| 朝外 J4=180、J5=90 | 0 / 56 | 无 | 10 mm |

选择175°作为收纳候选，而非将200°设为硬件限位。这个结果说明朝外腕有进一步折叠空间；不证明166°一定有足够公差，也不证明采样点之间连续无碰撞。

## 分段展开路径

最大关节增量不超过3°的线性关节空间采样：

| 段 | 样本数（含端点） | 穿透/穿地样本 |
|---|---:|---:|
| STOW → SAFE_UNFOLD | 30 | 0 |
| SAFE_UNFOLD → WRIST_NEUTRAL | 31 | 0 |
| WRIST_NEUTRAL → WRIST_TURNED | 61 | 0 |
| WRIST_TURNED → HOME | 28 | 0 |

合计150次采样，含段间重复端点。motor间最小10 mm。仅验证这条指定路径，不代表可从收纳姿态任意同时转动六轴。没有验证带电运行、制动距离、负载挠度、连接器、连续扫掠和真实止挡。

## 蛋糕任务代表点

临时蛋糕顶面Z=200 mm，TCP竖直向下在Z=210 mm：

| 点 | TCP X / Y / Z（mm） | 自碰撞 |
|---|---|---|
| 近侧 | 400 / 70 / 210 | 无检测到穿透 |
| 中心接近 | 500 / 70 / 210 | 无检测到穿透 |
| 远侧 | 600 / 70 / 210 | 无检测到穿透 |
| 水平半径650 | 646.2198 / 70 / 210 | 无检测到穿透 |

半径650点使用J2≈21.139°、J3≈-14.642°、J5≈-96.496°，只说明该方向和高度在本运动链中可达。J3需跨到负角度，实际限位未知；HOME到该任务点的路径尚未检验。未将蛋糕/工装加入实体碰撞对，未验证完整圆周与路径，更没有证明带载能力。

## 原始证据

- `analysis/pose_checks.json`：主姿态穿透、近间隙、TCP。
- `analysis/motion_checks.json`：完整扫角、展开路径、任务点及不变量。
- `analysis/validation_summary.json`：采样汇总和首次失败样本。
- `analysis/export_checks.json`：FCStd/STEP重新读取验证。
- `analysis/gui_finish.log`：彩色FreeCAD文件保存记录。
- `analysis/reference_inventory.json`：参考仓库提交、文件类型和CAD清单。

后续任何电机、轴向位置、横向偏置、支架或工具更改，均需重新执行生成和检查。此报告是当前粗模的几何证据，不是安全或可制造认证。

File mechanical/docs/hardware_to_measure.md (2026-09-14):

# 实物待测清单

学校四方连接螺母块统一命名 FourWayNutBlock。用户于2026-09-14提供图片并明确指定M4采购版本，按表格第五行选型：`2-M4×8-H10×22`，长22 mm、截面10×10 mm，两个方向孔距均8 mm、M4、图示L3=5 mm。这些是图片标称值，状态为 `PROVISIONAL / IMAGE SPECIFICATION / MEASURE SCHOOL HARDWARE`，不是实物测量。孔深仍为null。

| 项目 | 记录要求 |
|---|---|
| 长、宽、高 | nut_block_size_x / y / z，mm |
| 螺纹规格 | nut_block_thread_size，分别确认两个方向是否一致 |
| 两对孔距 | nut_block_pair_A_spacing / pair_B_spacing，中心距 |
| 空间关系 | 两对孔轴方向、离边距离、所在高度及是否相交 |
| 螺纹孔深 | nut_block_hole_depth_A / B，区分钻孔深度与有效螺纹深度 |
| 是否贯通 | 每个方向分别记录 |
| 可用螺钉长度 | 结合夹层厚度，防止孔底顶死或两颗螺钉相碰 |
| 到货版本 | 型号、数量、材质、是否存在不同孔距或规格 |

独立目录中的 `FourWayNutBlock_PLACEHOLDER` 使用22×10×10 mm图片标称包络。两对孔示意轴相互垂直，孔深仅作展示，不可据此加工；正面离边位置和内孔是否相通必须实测。当前安装数量为0，作为候选标准件交接。

优先评估的连接为J2叉片到大臂、J3叉片到小臂、J4近端壳体到叉片及内部垂直结构。当前几何中可使用M4防松螺母，按用户说明，此件只用于两块独立板材的90°连接；当前叉片与端面、安装耳与底板等平行夹层用螺钉和防松螺母。整体打印的直角筋不增加五金接口。盒梁内部筋/侧壁为同一打印件，那里没有虚构可拆连接。

还需实测CyberGear的9-M3固定孔、6-M4输出孔、螺纹有效深度、止口、整体外形与连接器方向；实验台厚度和孔位；实际套筒/内六角尺寸。所有电机螺钉长度均TBD。轴承型号、金属材料、轴公差和夹紧传扭能力保留给下一阶段。

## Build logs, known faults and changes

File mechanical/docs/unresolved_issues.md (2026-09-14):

# arm_0 首次审图待解决事项

| 优先级 | 问题 | 待完成工作 |
|---|---|---|
| 1 | 既有电机自重分析给出J2水平重力矩下界约6.14 N·m，高于参考4 N·m额定转矩，尚未计结构/负载 | 后续单独确定负载、配重/减速或执行器；本轮不重做该方案 |
| 1 | 所有螺钉采购长度TBD，电机螺纹深度/止口/连接器未实测 | 实物量测后核算啮合、防顶底、垫圈叠层和锁紧螺母露牙 |
| 1 | 局部凹座、螺母退出槽和安装耳尚未完成强度核算，部分M4输出头凹座仅剩2 mm名义材料 | 审核剩余壁厚和金属材料；先做样件静态试装，不直接带载 |
| 1 | 管接头、短轴颈、一体腕部连接件和工具夹紧缺少最终预紧/止退/公差与疲劳证明 | 完成金属件工程图和夹紧传扭验证 |
| 2 | 轴承全为PLACEHOLDER，未采购定型 | 按载荷与寿命选择并重做配合、肩部与压盖 |
| 2 | 四方块按图片第五行2-M4×8-H10×22选为90°板材连接候选，当前安装0 | 采购后核对22×10×10、M4、双8 mm孔距、L3=5、前面离边及真实孔深/内部交孔 |
| 2 | 标准螺钉/垫圈/螺母只是保守外形，内六角直线工具35 mm预算 | 实测供应商、套筒、弯头扳手及手部空间，验证实际拆装顺序 |
| 2 | 启动路径为≤2°离散检查，尚未检查SAFE_UNFOLD至任务点完整路径 | 后续连续检测、速度/制动/限位与实机低速试验 |
| 2 | 8×5线槽未选线束、接插件或弯曲寿命 | 实测线径、出口、应变释放与动态弯曲 |
| 2 | 打印网格封闭不等于材料/层间强度合格 | 确定材料、朝向、收缩、支撑与首件尺寸检验 |

CAD有效、实体无相交、STEP回读通过均是几何结论。当前状态为首次审图，尚未获得生产、带载或整机安全发布结论。

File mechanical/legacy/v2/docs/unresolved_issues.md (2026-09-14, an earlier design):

# 第二阶段未解决问题

按下一轮决策顺序排列。当前文件是可试装工程粗模，不是制造发布包。

| 优先级 | 问题与证据 | 下一步 |
|---|---|---|
| 1 | 水平伸展仅四个远端电机对J2的重力矩下界6.627 N·m，超过参考额定4 N·m，尚无结构/负载余量 | 明确任务负载和姿态占空比，比较J2减速、弹簧/配重和重选电机；重新设计接口后再复查几何 |
| 1 | CyberGear前孔来自第三方STL提取与说明书图，实物修订/孔深/止口及端子角度未验证 | 实测固定9-M3和输出6-M4、3定位孔、止口、后盖、连接器；做单电机接口试片 |
| 1 | 输出hub/贯穿轴的抗转、轴向锁紧、预紧未定型，J1耦合面仍是连接概念 | 指定轴/夹紧/键及轴承内外圈固定，补剖面与加工图，确认扭矩路径 |
| 2 | J2/J3的20×42×12与J1的80×100×10轴承均为尺寸占位 | 确认型号、载荷、安装公差、同轴度和压盖受力面；0.2 mm余量不是最终配合 |
| 2 | 13份J1～J3封闭STL仅通过拓扑与尺寸检查 | 先打印孔/嵌件/轴承试块，再静态装配；选择材料、打印方向、支撑和层间受力方案 |
| 2 | J3长M4通道、嵌件规格和各叠层紧固件尚未形成采购BOM | 验证工具路径、螺钉供货与啮合深度，特别是转子有效孔深6 mm；补金属件和紧固件BOM |
| 2 | STOW=165°离散检查通过；168°/170°肩部轴承支撑撞J4壳，175°多处碰撞 | 若需更紧收纳，重排肩部支撑和腕部壳，再核查；不得直接放宽STOW角度 |
| 2 | 四姿态无穿透并不代表路径无碰撞；线缆预留方向未定 | 加机械限位、完整展开路径扫掠、线束弯曲/应变释放和真实螺钉工具包络 |
| 3 | 大/小臂中心横向相隔132 mm，支架较宽；腕部仍占收纳空间 | 在真实电机/支承明确后缩短轴向叠层，维持320/290/60/35中心距 |
| 3 | J4～J6仅为可信装配占位，尚无完整支承和装配制造细节 | J1～J3验证后再完善腕部，不直接据当前占位加工 |
| 3 | 未与ArmDesigner源码核对零位/转向/坐标；envelope为保守局部盒 | 回导时用bridge的局部刚体变换对齐并做回归；不用详细STL代替轻量碰撞体 |
| 3 | Thor官方装配网页超时，Art4/Art56聚合包围盒异常 | 人工在FreeCAD检查相关链接/辅助基准；不把当前审查当成完整装配验证 |
| 3 | CyberGear未发现LICENSE；用户原始SLDASM/Y-arm来源未确认 | 保留来源和提交号，商业发布前向权利方核对授权，不把“无LICENSE”理解为许可 |

当前四个已保存姿态未检出实体穿透；上述168°/170°/175°是明确不通过的试验姿态。仍未做最终静力/挠度、寿命、热分析、最终有限元或带载试验。需要人工FreeCAD继续处理的重点为轴/轴承剖面、螺钉锁紧与工具通道、支架横向压缩及后续腕部结构。

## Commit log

2026-09-14 Add independent robot arm CAD and exclude reference assets
    [Arm_v1_CAKE_APPROACH.FCStd, Arm_v1_CAKE_APPROACH.step, Arm_v1_EXTENDED.FCStd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]
2026-09-14 Rebuild arm_0 V3 topology and compact serial wrist
    [Forearm_CentralBox.stl, Forearm_RemovableCover.stl, J1_BaseTray.stl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]
2026-09-14 Freeze Prototype 0 fasteners and prepare SolidWorks review handoff
    [Forearm_CentralBox.stl, Forearm_RemovableCover.stl, J1_BaseTray.stl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]
